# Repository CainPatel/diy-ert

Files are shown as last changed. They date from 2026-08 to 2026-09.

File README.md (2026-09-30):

# diy-ert

<!-- photo of the breadboard build / field setup goes here -->

A four electrode earth resistivity meter (Wenner array) built from scratch
in about a month, for roughly $150 in parts. Commercial instruments that
make the same measurement start above $20,000.

This repo is written as an engineering log. Four ADS1115 ADCs died during
development, all from the same root cause, and the
[failure log](docs/failure-log.md) is probably the most useful file here.
Read it before powering anything up.

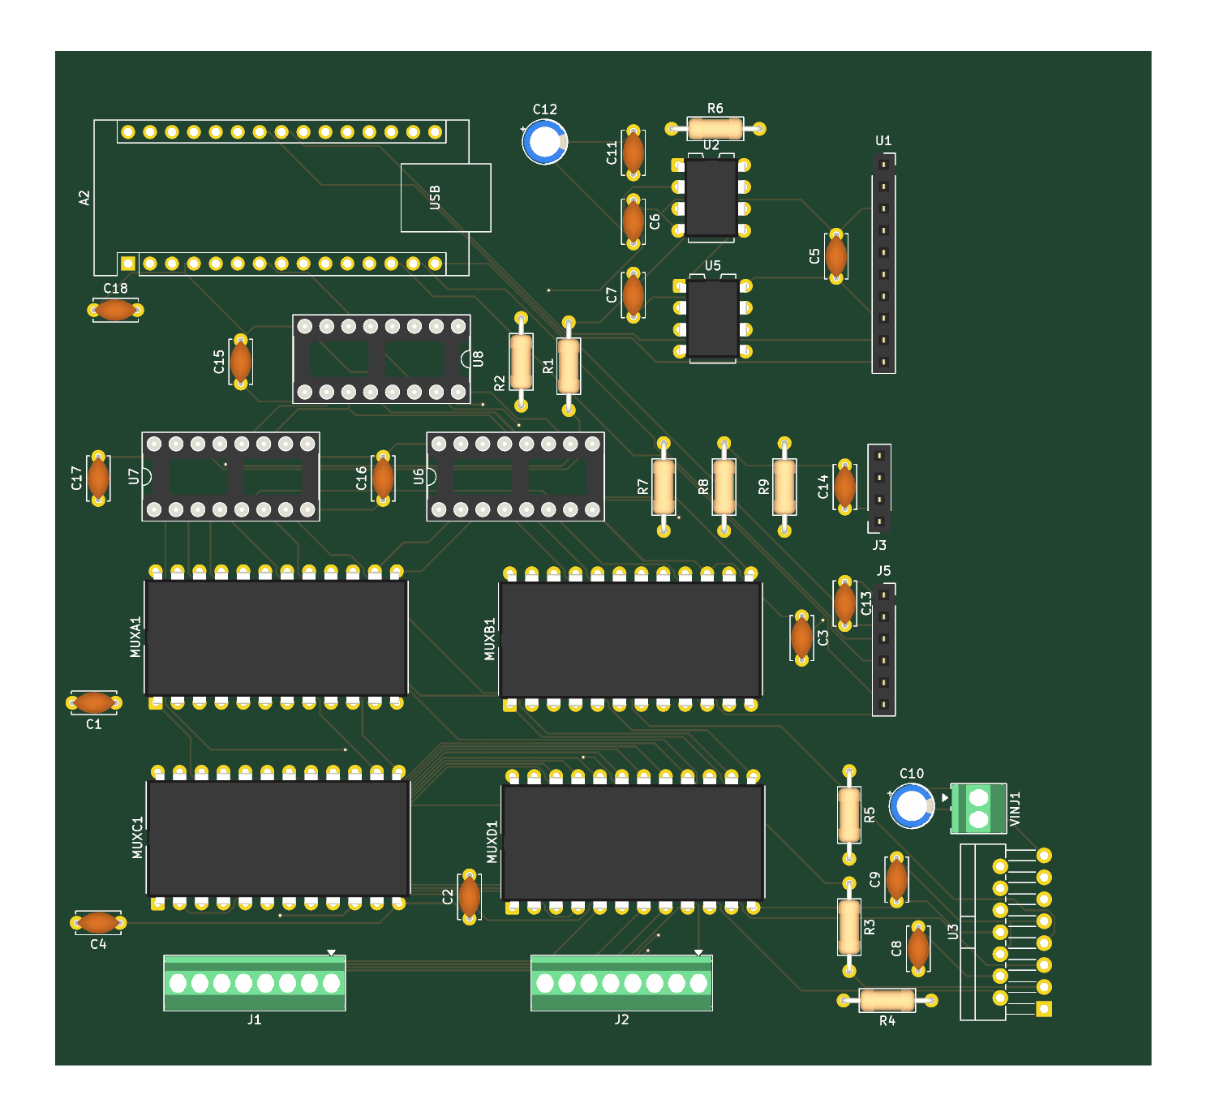
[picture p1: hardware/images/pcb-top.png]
Custom PCB, top side


The custom PCB, designed after the breadboard build below produced its
results. KiCad sources, gerbers, renders and review notes are in
[hardware/](hardware/README.md).

## Results

| Test | Result |
|---|---|
| Bench, known 100 Ω resistor | measured 98.6 Ω (1.4% error) |
| Field, moist Georgia clay, a = 0.5 m | 71-72 Ω·m apparent resistivity, 1.24 mA injected |

No 2D image yet. What exists today is a validated single point measurement
and one good field reading, both from the breadboard build. Full status
below.

## How it works

Contact resistance is the whole problem. Where a steel rod meets soil this
build measured 40-80 kΩ, and a two electrode measurement puts that
directly in series with the tens of ohms of ground you actually want. So
the roles are split across four electrodes: current goes in through the
outer pair (C1, C2), and the voltage it creates in the ground is read
across a separate inner pair (P1, P2). The potential pair feeds an
instrumentation amplifier and draws essentially no current, so its contact
resistance drops no voltage and falls out of the result. On the current
side, contact resistance only limits how much current flows, and the
current is measured across a shunt rather than assumed.

From there it is Ohm's law: R = V/I, and apparent resistivity
ρ = 2πa·R for electrode spacing a. Details in [docs/theory.md](docs/theory.md).

```mermaid
flowchart LR
    mega[Arduino]
    bridge[L298N H-bridge]
    muxa[MUX A]
    muxb[MUX B]
    muxcd[MUX C and D]
    amp[AD620]
    shunt["1 kΩ shunt"]
    adc[ADS1115]
    earth((earth))

    mega -->|IN1, IN2| bridge
    bridge --> muxa -->|C1| earth
    earth -->|C2| muxb --> shunt --> bridge
    earth -->|P1, P2| muxcd --> amp -->|A0| adc
    shunt -.->|A2, A3| adc
    adc -.->|I2C| mega
```

The H-bridge flips the injection polarity every ~150 ms. Differencing the
two half cycles cancels electrode self-potential and amplifier offset, and
stacking 20 cycles averages the noise down. The AD620 stage gain is 76 on
the breadboard build, measured with a multimeter during calibration rather
than taken from the trimmer setting. Four 16-channel muxes let any of 16
electrodes play any of the four roles.

## Status

- [x] Bench validation against a known resistor
- [x] One field reading
- [x] 16 channel electrode switching built on the breadboard, 12 of 16
      channels working (contact faults, see the failure log)
- [x] Automated Wenner survey firmware, outputs pyGIMLi format
- [x] Custom PCB designed: Arduino Nano plus shift registers, 2 layers,
      DRC clean, gerbers generated, firmware written and compiled
- [x] PCB fabricated, assembled and brought up (one design issue to settle
      first, see the review notes in [hardware/](hardware/README.md))
- [ ] Non-polarising potential electrodes (steel rods drift within minutes)
- [ ] 2D survey of real ground

## Documentation

In reading order:

1. [Theory](docs/theory.md): Ohm's law through the ground, Wenner
   geometry, why the polarity alternates, why stacking works
2. [Hardware](docs/hardware.md): the signal chain, wiring reference, and
   five design constraints learned the hard way
3. [Calibration](docs/calibration.md): the offset/gain procedure in the
   order that converges, with the numbers from this build
4. [Failure log](docs/failure-log.md): symptom, root cause, and fix for
   every failure, including the four dead ADCs
5. [Field procedure](docs/field-procedure.md): how the field reading was
   taken and what limits survey duration
6. [Build guide](docs/assembly.md): power, physical layout, every
   connection pin by pin, assembly order, pre-power checklist
7. [Software guide](docs/software.md): toolchain, uploading, the
   bring-up walkthrough, capturing a survey, running the inversion
8. [Firmware](firmware/README.md): seven bring-up sketches for the
   breadboard and one for the PCB. Run them in order.
9. [PCB](hardware/README.md): the board, what changed from the
   breadboard, shift register wiring, BOM, fabrication, review notes

## Repository layout

```
diy-ert/
├── docs/          theory, hardware, calibration, failure log, field
│                  procedure, build guide, software guide
├── firmware/      bring-up sketches 00-06 (Mega breadboard), 07 (Nano PCB)
├── hardware/      PCB: KiCad sources, gerbers, renders, schematic PDF,
│                  BOM, DRC/ERC reports
├── analysis/      pyGIMLi inversion script, capture cleaner, format notes
└── data/          data format spec and the one validated field reading
```

## Cost

Roughly $150 in parts including spares. The PCB bill of materials is in
[hardware/README.md](hardware/README.md); the parts that are not on the
board (rods, supply, wire, the breadboard-only trimmers) are listed in
the [build guide](docs/assembly.md).

## License

MIT, see [LICENSE](LICENSE).

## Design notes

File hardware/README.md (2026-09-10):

# Hardware

The electrical design and the breadboard wiring reference are in
[docs/hardware.md](../docs/hardware.md); the physical build guide for
both versions is [docs/assembly.md](../docs/assembly.md). This directory
holds the custom PCB: KiCad sources, fabrication files, reports, images,
and the bill of materials.

PCB, top side

## Status

- [x] Schematic complete; ERC run, 5 errors and 22 warnings, all explained below
- [x] Layout routed on 2 layers; DRC clean apart from one silkscreen overlap
- [x] Gerbers and drill file generated from the board sources
- [ ] Boards fabricated
- [ ] Board assembled and brought up with [sketch 07](../firmware/07_pcb_console/)
- [ ] Bench result reproduced on the PCB (98.6 Ω on the 100 Ω reference)

Before ordering, read the review notes at the end of this page. One of
them (the ADS1115 socket pin order) needs a decision.

## Board at a glance

| | |
|---|---|
| Tool | KiCad 10.0.5, sources in [kicad/](kicad/) |
| Size | 127.05 x 117.55 mm, 2 layers, 1.6 mm FR4 |
| Parts | 44 footprints, all through-hole; every IC in a DIP socket |
| Controller | Arduino Nano v3 on headers, powered over USB |
| Control lines | 3 (SER, SRCLK, RCLK) into a chain of three 74HC595s, replacing the Mega's 18 direct pins |
| Design rules | 0.2 mm track, 0.15 mm clearance, 0.6 mm vias, 0.5 mm copper-to-edge |
| Copper | ground pour on the bottom layer, 840 track segments, 17 vias |
| Connectors | two 8-way screw terminals for electrodes E0-E15, 2-way screw terminal for the injection supply, I2C header, SPI header |
| Reports | [reports/drc.rpt](reports/drc.rpt), [reports/erc.rpt](reports/erc.rpt) |
| Schematic | [schematic.pdf](schematic.pdf), [images/schematic.png](images/schematic.png) |
| BOM | [bom.csv](bom.csv), exported from the schematic |

## What changed from the breadboard

| | Breadboard (validated) | PCB |
|---|---|---|
| Controller | Arduino Mega, 18 direct control pins | Arduino Nano, 3 pins into three 74HC595 shift registers |
| Bridge control | two Mega pins to L298N IN1/IN2 | U8 outputs QA/QB to IN1/IN2 |
| L298N | driver module | bare L298N (Multiwatt-15) on the board, EnA tied high, bridge B unused |
| Amplifier gain | 10 kΩ trimmer, measured 76 | fixed R6 = 1 kΩ, 50.4 nominal, no trimmer |
| Offset / reference | trimmer into the LM358 buffer | fixed 10k/10k divider (R7/R8) into the LM358 buffer, 2.5 V |
| ADS1115 | breakout on the breadboard | same breakout plugged into a 10-pin socket, U1 |
| Protection | 10 kΩ on ADC inputs | 10 kΩ on every ADC input (R4, R5, R9) and both amplifier inputs (R1, R2) |
| Electrodes | jumper wires | screw terminals J1 (E0-E7), J2 (E8-E15) |
| Decoupling | some | 100 nF at every IC, 10 µF on the 5 V rail, 100 µF + 100 nF on the injection supply |

No trimmers means calibration on the PCB reduces to measuring the gain
(step 4 of [docs/calibration.md](../docs/calibration.md)). If the
amplifier saturates, lower the injection voltage or increase R6.

## Floorplan

Top view, matching the render above. The Nano sits in the top-left
corner with its USB connector facing into the board. The three shift
registers are below it (U8 directly under the Nano, U7 and U6 in a row
beneath). The analog front end is in the top-right: the AD620 (U2) with
its gain resistor R6 above it, the LM358 reference buffer (U5) below it,
and the ADS1115 socket (U1) at the right edge. The sense-side protection
resistors R1/R2 sit between the shift registers and the amplifier; the
reference divider R7/R8 and the output protection R9 are to their right.
The four muxes form a 2x2 block in the lower half (A and B on top, C and
D below) with the electrode terminals J1 and J2 on the bottom edge
directly beneath them. The injection parts are grouped in the
bottom-right corner: the L298N (U3, upright at the right edge), the
injection terminal VINJ1, the 100 µF bulk capacitor C10, the shunt R3,
and its protection resistors R4/R5. The I2C header J3 and SPI header J5
are on the right edge, mid-board.

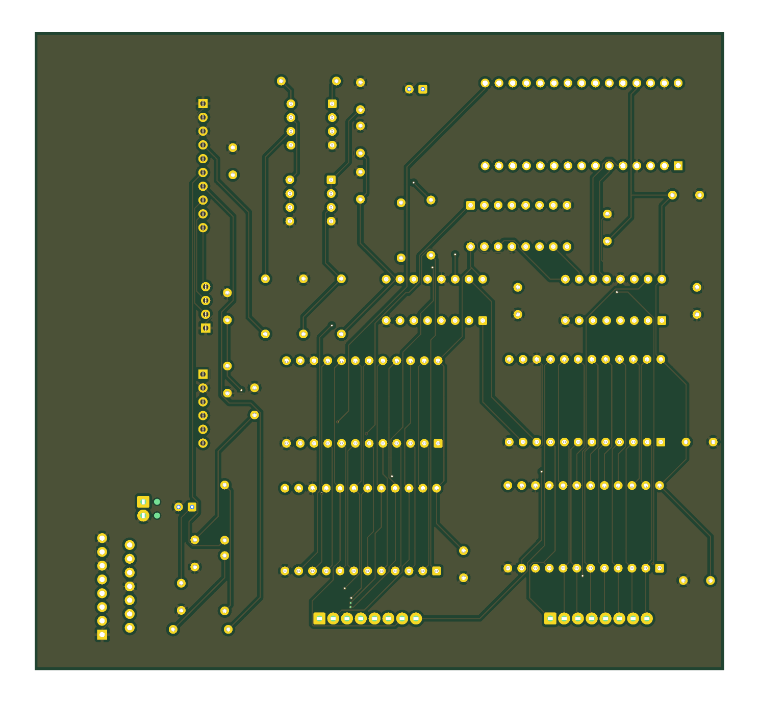
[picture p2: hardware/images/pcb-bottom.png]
PCB, bottom side


## Shift register chain

This is the part the firmware has to get right.

Nano D2 clocks SRCLK on all three registers, D3 clocks RCLK on all three,
and D4 feeds SER of U6. U6's QH' feeds U7's SER, and U7's QH' feeds U8's
SER. Output enable (~OE) is tied to ground on all three, so the outputs
are always driven; ~SRCLR is tied to 5 V.

| Register | Outputs | Drives |
|---|---|---|
| U6 | QA, QB, QC, QD | MUX A (C1) S0, S1, S2, S3 |
| U6 | QE, QF, QG, QH | MUX B (C2) S0, S1, S2, S3 |
| U7 | QA, QB, QC, QD | MUX C (P1) S0, S1, S2, S3 |
| U7 | QE, QF, QG, QH | MUX D (P2) S0, S1, S2, S3 |
| U8 | QA, QB | L298N IN1, IN2 |
| U8 | QC-QH | unused |

Shifting 24 bits MSB-first, U8's byte first, then U7's, then U6's, puts
bit 0 of each byte on that register's QA. So U6's byte is
`chA | (chB << 4)`, U7's is `chC | (chD << 4)`, and U8's is
`IN1 | (IN2 << 1)`. Sketch 07 does exactly this in `latch()`.

## Nano pin map

| Nano | Net |
|---|---|
| D2 | 74HC595 SRCLK (all three) |
| D3 | 74HC595 RCLK (all three) |
| D4 | 74HC595 SER, into U6 |
| A4, A5 | I2C SDA, SCL: ADS1115 and header J3 |
| D10, D11, D12, D13 | SPI CS, MOSI, MISO, SCK: header J5 only, unused by the firmware |
| 5V, GND | board logic supply, from the Nano's USB |
| VIN, 3V3, D0-D1, D5-D9, A0-A3, A6-A7 | not connected |

## Connectors

| Ref | Type | Pin 1 to pin N |
|---|---|---|
| J1 | 8-way screw terminal, 2.54 mm | E0, E1, E2, E3, E4, E5, E6, E7 |
| J2 | 8-way screw terminal, 2.54 mm | E8, E9, E10, E11, E12, E13, E14, E15 |
| VINJ1 | 2-way screw terminal | injection supply +, GND |
| J3 | 1x4 socket | GND, 5V, SDA, SCL |
| J5 | 1x6 socket | 5V, GND, MISO (D12), MOSI (D11), SCK (D13), CS (D10) |
| U1 | 1x10 socket | see the review notes below before fitting a breakout |

## Bill of materials

From the KiCad schematic ([bom.csv](bom.csv)), with approximate
single-unit prices.

| Ref | Qty | Part | Package | ~Price |
|---|---|---|---|---|
| A2 | 1 | Arduino Nano v3 (clone) | module, on 1x15 headers | $5 |
| U1 | 1 | ADS1115 breakout | 1x10 socket | $10 |
| U2 | 1 | AD620AN | DIP-8 | $10 |
| U3 | 1 | L298N | Multiwatt-15 (TO-220-15), vertical | $3 |
| U5 | 1 | LM358 | DIP-8 | $1 |
| U6, U7, U8 | 3 | 74HC595 | DIP-16 | $1 ea |
| MUXA1-MUXD1 | 4 | CD74HC4067E | DIP-24 | $2 ea |
| R1, R2, R4, R5, R7, R8, R9 | 7 | 10 kΩ | axial | |
| R3 | 1 | 1 kΩ 1%, shunt | axial | |
| R6 | 1 | 1 kΩ, AD620 gain | axial | |
| C1-C9, C11, C13-C18 | 16 | 100 nF ceramic | 5 mm disc | |
| C10 | 1 | 100 µF electrolytic | radial, 2.5 mm pitch | |
| C12 | 1 | 10 µF electrolytic | radial, 2.5 mm pitch | |
| J1, J2 | 2 | 8-way screw terminal, 2.54 mm (Phoenix MPT 0,5/8) | | $2 ea |
| VINJ1 | 1 | 2-way screw terminal, 2.54 mm | | $1 |
| J3, J5 | 2 | 1x4 and 1x6 pin sockets | | |
| | 9 | DIP sockets: 2x 8-pin, 3x 16-pin, 4x 24-pin | | $3 |
| | 1 | bare 2-layer PCB from any prototype fab | | $5-10 for five |

Breadboard-only extras (trimmers, breadboards, jumpers) and the parts
common to both builds (electrode rods, 12 V supply, wire) are in
[docs/assembly.md](../docs/assembly.md). The whole build still lands
near $150.

## Fabrication

[gerbers/](gerbers/) has the seven layer files, the drill file, and the
job file, generated from `kicad/diy-ert.kicad_pcb` with `kicad-cli` (the
exact commands are in [kicad/README.md](kicad/README.md)). Zip the
directory and upload it; the board needs nothing beyond any prototype
fab's defaults: 2 layers, 1.6 mm, 0.2 mm minimum track, 0.15 mm
clearance, HASL finish is fine.

The set exported on 2026-08-29 predates the last save of the board file
by a couple of hours, so the committed set is regenerated from the board
as saved. Compared line by line with aperture numbering normalised, the
two sets are geometrically identical: same apertures, same pads, same
tracks on every layer. The only difference is one unused aperture
selection in the older copper and mask files.

## History

- 2026-08-22 to 08-24: schematic drawn around the Mega, netlist exported
  repeatedly while footprints were assigned and the amplifier stage
  added.
- Around 08-25: a 4-layer layout attempt. An autorouter round trip
  produced 686 DRC violations (201 net shorts, 199 dangling tracks) from
  a layer-mapping mismatch on re-import. Lesson: autorouters do not know
  which nets are noise-sensitive; hand-route the analog paths and lock
  them, or hand-route everything on a board this size.
- 2026-08-29: redesign around the Nano and three 74HC595s, taking the
  control pin count from 18 to 3. Two-layer layout, Freerouting DSN
  export, DRC with one silkscreen warning, gerbers exported, board saved.

## Review notes

Things noticed while reading the design files for this write-up. None
have been tested on a physical board yet.

1. **ADS1115 socket pin order.** U1 uses the ADS1115 chip symbol with a
   1x10 pin-socket footprint, so the socket pins follow the IC's pin
   numbering: ADDR, ALERT, GND, A0, A1, A2, A3, VDD, SDA, SCL from pin 1
   to pin 10. The common breakout modules (Adafruit and the clones) have
   their header in the order VDD, GND, SCL, SDA, ADDR, ALRT, A0, A1, A2,
   A3. Plugged straight in, a standard breakout would put its VDD on the
   pad that is wired to ground. Before ordering, either swap the symbol
   for one that matches the breakout header, or plan on an adapter
   between the socket and the module. Check your specific module's
   silkscreen against this list.
2. **Shift register outputs at power-on.** ~OE is tied to ground on all
   three 74HC595s, so their outputs drive the mux select lines and the
   L298N inputs from the moment power arrives, with undefined contents,
   until the firmware latches a state. Sketch 07 does that first thing in
   `setup()`, but the Nano bootloader runs for about a second before it.
   A future revision could drive ~OE from a Nano pin with a pull-up so
   the outputs stay high-impedance until the firmware takes over. Until
   then, power the logic before connecting the injection supply.
3. **Fixed gain.** R6 = 1 kΩ gives a nominal gain of 50.4 with the
   reference at 2.5 V. The field reading of 28.5 mV across P1-P2 would
   swing the output by about 1.4 V either side of 2.5 V, which is inside
   the AD620's output range on a 5 V supply but not by a lot. Larger
   signals need a lower injection voltage or a larger R6. The `t`
   command in sketch 07 flags readings near the rails.
4. **C10 polarity.** C10 (100 µF on the injection supply) is drawn with a
   plain capacitor symbol but has a polarised footprint. Fit it with the
   positive lead to the VINJ1 side.
5. **I2C pull-ups.** There are none on the board; the ADS1115 breakout
   provides them. A bare chip in U1 would need them added.
6. **Silkscreen.** The one DRC warning is U2's reference designator
   overlapping R6's outline. Cosmetic.
7. **ERC.** The five errors are all "pin not driven": the Nano's VIN,
   both RESET pins, and AREF (unused, normal for that symbol), and the
   L298N's Vs, which enters through the VINJ1 connector and would be
   silenced by a PWR_FLAG on that net. The warnings are unused pins
   (Nano, L298N bridge B, ADS1115 ALERT, U8 QC-QH), one short wire stub
   near the Nano's 3V3 pin, and "Vss not connected to ground": the KiCad
   L298N symbol names its logic-supply pin Vss, and it is correctly on
   5 V.
8. **Track width.** 0.2 mm everywhere, including the 5 V and injection
   paths. Fine for the currents involved (about a milliampere of
   injection, tens of milliamperes of logic) and for any fab, but thin
   for hand rework. A future revision could widen the supply traces.

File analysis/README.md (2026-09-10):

# Analysis

Inversion of survey output with [pyGIMLi](https://www.pygimli.org/), and
a helper for turning a raw serial capture into a data file.

## Install and run

pyGIMLi installs cleanly through conda:

```
conda create -n ert -c gimli -c conda-forge pygimli
conda activate ert
python invert_pygimli.py survey.dat        # lam = 20
python invert_pygimli.py survey.dat 50     # smoother
```

`clean_capture.py` needs only Python:

```
python clean_capture.py capture.txt survey.dat
```

It keeps the data block (from the electrode-count line to the closing
`0`) and drops the banner and command replies that sketch 07 prints
around it. Sketch 06 prints nothing but the data, so its capture can be
used directly.

## Data format

Firmware sketches 06 and 07 emit pyGIMLi's unified data format directly:

```
12
# x z
0.00 0.0
0.50 0.0
...
18
# a b m n rhoa
1 4 2 3 72.196
...
0
```

- The header block declares the electrode positions in metres (12
  electrodes at 0.5 m spacing for the breadboard build's working
  channels; 16 by default on the PCB).
- Each data row is `a b m n rhoa`. **a/b are the current electrodes, m/n
  are the potential pair**, and electrode numbers are **1-indexed**. An
  off-by-one here does not error out; it silently produces a wrong but
  plausible-looking model.
- `rhoa` is apparent resistivity in Ω·m, computed in the firmware as
  2πa·R from the measured V and I.
- The trailing `0` is the empty topography block.

## Regularisation

The surveys are small: 12 working electrodes give 9 + 6 + 3 = 18 Wenner
readings across three spacings, and 16 electrodes give 35 across five.
With that little data the regularisation parameter `lam` matters a great
deal. Too low and the inversion fits noise, producing structure that is
not in the ground. The default is `lam=20`. A useful habit with data
this sparse: treat any feature that disappears when you double `lam` as
an artefact.

## Status

The pipeline is written against the firmware's output format but has not
been run on a real 2D field dataset. The instrument so far has one
validated single point field reading, not a survey. See the
[repository README](../README.md).

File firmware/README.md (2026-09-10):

# Firmware

Seven sketches that bring the breadboard instrument up one verified
subsystem at a time, plus one sketch for the custom PCB. The end-to-end
walkthrough (toolchain, uploading, what to type, capturing output) is in
[docs/software.md](../docs/software.md).

> [!WARNING]
> **Run the sketches in order.** Every hardware failure on this project,
> including four destroyed ADS1115s, came from powering up an unverified
> circuit. Each sketch verifies one subsystem against an independent
> reference (a multimeter, a known resistor) before the next subsystem
> goes on top.

| # | Sketch | Board | Verifies | Failure signature |
|---|---|---|---|---|
| 00 | [I2C scanner](00_i2c_scanner/) | Mega or Nano | ADC is alive at 0x48 | nothing found: check power, SDA/SCL, solder |
| 01 | [Raw ADC readout](01_raw_adc/) | Mega or Nano | ADC reads a known voltage correctly | raw counts near 0 on A2/A3: shunt sense wires disconnected |
| 02 | [DC hold](02_dc_hold/) | Mega | H-bridge switches; lets a multimeter settle | trace voltage along the path, find where it disappears |
| 03 | [Mux channel scan](03_mux_scan/) | Mega | Address decoding and channel continuity | all channels identical: read the mux output directly, not through the amp |
| 04 | [Live amp tuning](04_amp_tuning/) | Mega | Amp operating in range | both halves near 3.6 V: saturated, adjust offset first, not gain |
| 05 | [Single measurement](05_single_measurement/) | Mega | Whole chain, against a known resistor | should report ~100 Ω on a 100 Ω target |
| 06 | [Wenner survey](06_wenner_survey/) | Mega | Full sequence over working channels | outputs pyGIMLi format rows |
| 07 | [PCB console](07_pcb_console/) | Nano (PCB) | steps 01-06 as serial commands, through the shift registers | see its README |

Sketches 00-06 are the breadboard build (Arduino Mega, 18 direct control
pins). Sketch 07 is the PCB (Arduino Nano, 3 pins into three 74HC595
shift registers), where one sketch with a command per step replaces
02-06; 00 runs unchanged on the Nano first.

All eight compile cleanly with arduino-cli 1.5 and AVR core 1.8.8
(00-06 for `arduino:avr:mega`, 00, 01 and 07 for `arduino:avr:nano`).

## Requirements

- Arduino IDE or arduino-cli, with the **Adafruit ADS1X15** library
  installed (Library Manager, search "Adafruit ADS1X15"; accept the
  Adafruit BusIO dependency). Sketches 00, 02 and 03 need only the core
  libraries.
- Serial monitor at 9600 baud.
- Some Arduino IDE versions refuse sketch folders that start with a
  digit. If yours does, rename the folder and the `.ino` together (for
  example `s00_i2c_scanner/s00_i2c_scanner.ino`) and keep the ordering
  prefix.

## Pin map, breadboard (Arduino Mega)

| Function | Pins |
|---|---|
| L298N IN1 / IN2 | 6, 7 |
| Mux C1, address S0-S3 | 22, 24, 26, 28 |
| Mux C2, address S0-S3 | 30, 32, 34, 36 |
| Mux P1, address S0-S3 | 38, 40, 42, 44 |
| Mux P2, address S0-S3 | 46, 48, 50, 52 |
| ADS1115 | SDA = 20, SCL = 21, address 0x48; A0 = amp output, A2/A3 = shunt |

18 control pins total (16 mux address lines + 2 bridge inputs).

## Pin map, PCB (Arduino Nano)

| Function | Pins |
|---|---|
| 74HC595 SRCLK, RCLK, SER | D2, D3, D4 |
| ADS1115 | SDA = A4, SCL = A5, address 0x48 |
| Mux select lines and L298N IN1/IN2 | from the shift registers; chain order and bit layout in [hardware/README.md](../hardware/README.md) |

## Implementation details that carry the lessons

These are deliberate. Keep them if you modify the code:

- The stacking accumulators are explicitly initialised to zero.
  Uninitialised floats in C++ contain garbage, and garbage accumulated
  over 20 cycles looks like a plausible measurement. This bug happened.
- The shunt is read in both polarities and the magnitudes averaged, so
  bridge asymmetry and differential offset average out of the current
  value.
- The bridge is parked with both inputs LOW between measurements, to
  limit electrode polarisation
  ([docs/field-procedure.md](../docs/field-procedure.md)).
- The survey runs from `loop()` behind a done-flag, not from `setup()`,
  and waits for a start command, so output is not lost if the serial
  monitor opens late.
- A `CH[]` lookup table maps physical electrode position to a working mux
  channel, so dead channels are invisible to the survey logic:

```cpp
// Working channel map from the physical build
// Dead: 0, 7, 11, 12 (breadboard contact faults)
const int CH[12] = {1,2,3,4,5,6,8,9,10,13,14,15};
```

- On the PCB, `setup()` latches a parked bridge into the shift registers
  before anything else, because their outputs are live from power-on
  with undefined contents.

## Calibration constants

`AMP_GAIN` is a measured value, not a design constant: 76 on the
breadboard build, (3.5483 - 0.8205) / 0.0358; 50.4 nominal on the PCB
from R6 = 1 kΩ, to be measured. Run the procedure in
[docs/calibration.md](../docs/calibration.md) and substitute your own
value. Same for the shunt: measure its actual resistance rather than
trusting the band code.

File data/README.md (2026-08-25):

# Data

## Format

Two kinds of records belong in this directory:

**Survey files (`*.dat`):** the verbatim serial capture from firmware
sketch 06, in pyGIMLi's unified data format. The layout is documented in
[analysis/README.md](../analysis/README.md).

**Single manual readings:** commented blocks, one per measurement,
carrying every raw value needed to recompute the result:

```
# Wenner array, a = 0.5 m, Georgia clay soil, moist
# I = 1.24 mA, V(P1-P2) = 28.5 mV
# R = 22.98 Ω, ρ = 2πaR = 72.20 Ω·m
```

Each number states how it was obtained. `I` is measured across the 1 kΩ
shunt. `V(P1-P2)` is the stacked, offset-cancelled amplifier reading
divided by the measured gain. `R = V/I`. `ρ = 2πaR` is computed from
those, not measured.

## The one validated field reading

The block above is it, the single successful field measurement this
instrument has produced: Wenner array at a = 0.5 m in moist Georgia
clay, 1.24 mA injected, 28.5 mV across the potential pair, giving
R = 22.98 Ω and an apparent resistivity of 72.20 Ω·m.

## Known caveat: polarisation drift

Readings drifted from 71 to 90 Ω·m over several minutes as the steel
potential electrodes polarised. The 71-72 Ω·m value is the prompt
reading, taken before drift set in. Non-polarising copper sulphate
electrodes are the standard fix and are cheap to build. Until then, the
drift bounds how long a survey can run before it turns into a false
gradient in the data. Details in
[docs/field-procedure.md](../docs/field-procedure.md).

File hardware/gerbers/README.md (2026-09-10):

# Fabrication files

Generated from `../kicad/diy-ert.kicad_pcb` with `kicad-cli` (commands in
[../kicad/README.md](../kicad/README.md)).

| File | Layer |
|---|---|
| `diy-ert-F_Cu.gbr`, `diy-ert-B_Cu.gbr` | top and bottom copper |
| `diy-ert-F_Mask.gbr`, `diy-ert-B_Mask.gbr` | solder mask |
| `diy-ert-F_Silkscreen.gbr`, `diy-ert-B_Silkscreen.gbr` | silkscreen |
| `diy-ert-Edge_Cuts.gbr` | board outline |
| `diy-ert.drl` | Excellon drill, plated and non-plated together |
| `diy-ert-job.gbrjob` | job file: stackup, size, design rules |

To order: zip this directory and upload it. 2 layers, 1.6 mm,
127.05 x 117.55 mm, 0.2 mm minimum track, 0.15 mm clearance. Read the
review notes in [../README.md](../README.md) first.

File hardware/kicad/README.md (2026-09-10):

# KiCad project

KiCad 10.0.5 sources for the diy-ert board.

| File | What |
|---|---|
| `diy-ert.kicad_pro` | project settings, design rules, net classes |
| `diy-ert.kicad_sch` | schematic, one A4 sheet |
| `diy-ert.kicad_pcb` | board, 2 layers, 127.05 x 117.55 mm |

Open `diy-ert.kicad_pro` in KiCad 10 or newer. Every symbol and footprint
comes from the standard KiCad libraries, so nothing else needs installing.
The `.kicad_prl` file (per-machine view settings) and the `.history/`
backup directory that KiCad creates are ignored by git.

The project was drawn under the default name `Untitled` and renamed here;
the rename touched only the project-name strings in the files, and the
netlist, ERC, DRC, and gerbers exported from the renamed project match the
originals.

## Regenerating the exports

Everything in the parent directory (schematic PDF, board renders, BOM,
reports, gerbers) is produced from these sources with `kicad-cli`:

```
kicad-cli sch export pdf -o ../schematic.pdf diy-ert.kicad_sch
kicad-cli sch export bom -o ../bom.csv --fields "Reference,Value,Footprint,\${QUANTITY}" --group-by "Value,Footprint" diy-ert.kicad_sch
kicad-cli sch erc -o ../reports/erc.rpt --severity-all diy-ert.kicad_sch
kicad-cli pcb drc -o ../reports/drc.rpt --severity-all diy-ert.kicad_pcb
kicad-cli pcb render -o ../images/pcb-top.png --side top --width 1500 --height 1400 diy-ert.kicad_pcb
kicad-cli pcb render -o ../images/pcb-bottom.png --side bottom --width 1500 --height 1400 diy-ert.kicad_pcb
kicad-cli pcb export gerbers -o ../gerbers/ --no-protel-ext --layers "F.Cu,B.Cu,F.SilkS,B.SilkS,F.Mask,B.Mask,Edge.Cuts" diy-ert.kicad_pcb
kicad-cli pcb export drill -o ../gerbers/ diy-ert.kicad_pcb
```

On macOS `kicad-cli` lives at
`/Applications/KiCad/KiCad.app/Contents/MacOS/kicad-cli`.

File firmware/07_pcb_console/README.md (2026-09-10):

# 07: PCB console

**Target:** the custom PCB in [hardware/](../../hardware/), Arduino Nano.
Sketches 00-06 target the Mega breadboard build and drive the mux select
lines and the H-bridge from 18 direct pins. On the PCB those 18 lines come
from three chained 74HC595 shift registers on 3 Nano pins, so the PCB gets
one sketch with a serial command for each bring-up step instead.

**Board selection:** Arduino Nano. Most clones need Processor set to
"ATmega328P (Old Bootloader)".

**Commands** (9600 baud, any line ending):

| Command | Does | Replaces breadboard sketch |
|---|---|---|
| `?` | print this list | |
| `r` | one raw ADC readout: A0 and A2-A3, counts and volts | 01 |
| `p` | park the bridge, both L298N inputs low | 02 |
| `+` / `-` | hold the bridge forward / reverse in DC, for multimeter work | 02 |
| `c N` | put all four muxes on channel N (0-15) | 03 |
| `x A B C D` | set channels individually: C1=A, C2=B, P1=C, P2=D | |
| `t` | live amplifier readout, alternating polarity; any key stops | 04 |
| `m` | one stacked measurement on the current channels, prints R | 05 |
| `w` | Wenner survey over `CH[]`, prints a pyGIMLi data file | 06 |

Sketch 00 (I2C scanner) runs unchanged on the Nano and is still the first
thing to run.

**Constants to check before use:** `AMP_GAIN` (the PCB fixes the AD620
gain with R6 = 1 kΩ, 50.4 nominal; measure it per
[docs/calibration.md](../../docs/calibration.md)), `SHUNT_OHMS` (measure
R3), `ELECTRODE_SPACING`, and `CH[]` if the `c` scan finds a bad channel.

**Bring-up order on the PCB:** with no ICs fitted, check the 5 V rail.
Fit the Nano and the ADS1115 breakout, run sketch 00. Load this sketch,
`r` to confirm the ADC reads. Fit the shift registers and the L298N with
the injection supply off, `+`/`-`/`p` and confirm IN1/IN2 toggle at the
L298N pins. Fit the muxes, `c N` and beep out continuity from each mux
common pin to terminal E N. Fit the AD620 and LM358, `t` with the bench
chain. Then `m` on the known resistor. Details in
[docs/software.md](../../docs/software.md).

**What the suspect flag means:** `t` and `m` mark a reading as suspect
when the two half-cycles read nearly the same voltage (amplifier
saturated, or an input floating) or when the output sits within 0.2 V of
a rail. Both were real failure modes on the breadboard build. There are no
trimmers on the PCB: if the amp saturates, lower the injection voltage or
raise R6 to reduce the gain.

**Power-on note:** the 595 outputs are enabled from power-on (their
output-enable pin is tied to ground on the board) with undefined
contents. `setup()` latches a parked bridge and known mux channels first
thing, but the bootloader runs for about a second before that. Power the
logic before connecting the injection supply.

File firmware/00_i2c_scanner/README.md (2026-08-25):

# 00: I2C scanner

**Verifies:** the ADS1115 is alive and answering at address 0x48. Run
this before anything else. It needs only the Arduino, the ADS1115
breakout, and two I2C wires.

**Expected output:** `Device found at 0x48`, repeated every five seconds.

**Failure signature:** nothing found. Check, in this order:

1. Power to the breakout (VDD and GND with a multimeter, at the chip
   side of the header, not the wire side)
2. SDA/SCL wiring. Mega: SDA = pin 20, SCL = pin 21
3. The solder joints on the breakout headers

Press-fitted, unsoldered header pins pass visual inspection and fail
electrically. That exact fault produced several days of intermittent I2C
on this build ([docs/failure-log.md](../../docs/failure-log.md)).

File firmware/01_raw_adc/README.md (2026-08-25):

# 01: Raw ADC readout

**Verifies:** the ADS1115 converts a known voltage correctly, on the
inputs this instrument actually uses: A0 single-ended (amplifier output)
and A2/A3 differential (current shunt).

**How to use:** feed A0 a known voltage (the 2.5 V mid-rail node is
convenient) and confirm the printed value against a multimeter on the
same node. Then put a small DC current through the shunt (sketch 02 can
hold the bridge in DC) and check the A2-A3 differential the same way.
Requires the Adafruit ADS1X15 library.

**Failure signature:** raw counts near 0 on A2/A3 while current is
flowing means the shunt sense wires are disconnected.

Do not move on to the amplifier sketches until the ADC agrees with the
multimeter here. Every later sketch reads the world through this chip.

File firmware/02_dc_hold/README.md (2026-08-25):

# 02: DC hold

**Verifies:** the L298N H-bridge switches, and gives a multimeter a
signal it can actually read.

**Why it exists:** a multimeter cannot track a 150 ms square wave. It
averages toward zero and reports "no current" while the bridge is
driving perfectly well. That false reading cost real time on this build
([docs/failure-log.md](../../docs/failure-log.md)). Park the bridge in
DC and the multimeter is trustworthy again.

**How to use:** serial commands `+` (forward), `-` (reverse), `p`
(park). Hold a polarity and trace the voltage along the injection path
(supply, bridge OUT1/OUT2, mux input, electrode) until it disappears. A
jumper wire that had failed internally with no visible damage was found
exactly this way.

**Also worth doing here:** measure the actual voltage across OUT1-OUT2
at your working current. On this build the nominal 5 V supply delivered
only 3.8 V. The L298N's drop is current-dependent, and assuming the
nominal value produced a 45% error in computed resistance
([docs/hardware.md](../../docs/hardware.md), constraint 5).

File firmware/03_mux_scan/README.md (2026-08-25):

# 03: Mux channel scan

**Verifies:** address decoding and channel continuity on all four
CD74HC4067 multiplexers.

**How to use:** the sketch steps all four muxes through channels 0-15
together, two seconds per channel, announcing each on serial. For each
announced channel, continuity-beep from the mux's common pin to the
corresponding electrode header. Record every channel that fails.

**Failure signature:** all channels reading identically at the ADC. Read
the mux common pin directly with the multimeter, not through the
amplifier. A saturated amp makes every channel look the same regardless
of what the mux does (see the 3.62 V entry in
[docs/failure-log.md](../../docs/failure-log.md)).

**From this build:** channels 0, 7, 11 and 12 were dead. Breadboard
contact faults, not chip or addressing faults. The diagnostic that ruled
out the chips: in binary the dead channels are 0000, 0111, 1011 and
1100, which share no common address bit, so no single stuck address line
can explain them. The survey firmware routes around dead channels with
the `CH[]` lookup table ([firmware/README.md](../README.md)).

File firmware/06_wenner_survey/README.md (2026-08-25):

# 06: Wenner survey

**Runs:** the full automated measurement sequence over the 12 working
electrode channels, 18 measurements across three Wenner spacings (9 at
a = 0.5 m, 6 at 1.0 m, 3 at 1.5 m), and prints an inversion-ready
dataset in pyGIMLi's unified data format.

**How to use:** open the serial monitor, start logging to a file, then
send `s`. The survey runs from `loop()` behind a done-flag and waits for
the start command, so nothing is lost if the monitor attaches late. The
serial output is the data file; the sketch prints nothing else. Capture
it verbatim as `survey.dat` and feed it to
[analysis/invert_pygimli.py](../../analysis/invert_pygimli.py).

**The `CH[]` table** maps logical electrode position (0-11, twelve
equally spaced rods along the line) to a working mux channel, so the
dead channels (0, 7, 11, 12, breadboard contact faults) are invisible to
the survey logic and the field geometry stays uniform. If your build has
different dead channels, run sketch 03 and edit the table.

**Failure signature:** negative apparent resistivity values are
physically impossible. The amplifier railed in one polarity and produced
a fake differential. Go back to sketch 04, re-centre the offset, reduce
the gain ([docs/failure-log.md](../../docs/failure-log.md)).

**Status note:** the sequence runs and emits well-formed data over the
working channels, but a 2D field survey has not been done yet. See the
[repository README](../../README.md) for status and
[docs/field-procedure.md](../../docs/field-procedure.md) for the
electrode polarisation drift that currently bounds survey duration.

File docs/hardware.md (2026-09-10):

# Hardware

The signal chain, in the order the signal flows through it, plus enough
wiring detail to reproduce the breadboard build. The custom PCB that
implements the same circuit is documented in
[hardware/README.md](../hardware/README.md), with KiCad sources in
[hardware/kicad/](../hardware/kicad/); the full pin-by-pin connection
list for both builds is in [assembly.md](assembly.md).

## Signal chain

| Stage | Part | Role |
|---|---|---|
| Injection | L298N H-bridge | alternates polarity, driven from two Arduino pins |
| Current sense | 1 kΩ shunt, read differentially on ADS1115 A2/A3 | measures the actual injected current |
| Potential sense | AD620 instrumentation amplifier | rejects large common-mode, amplifies the mV differential |
| Reference | LM358 unity-gain buffer on a 10k/10k divider | holds the AD620 REF pin at mid-rail (2.5 V) |
| Digitisation | ADS1115, 16-bit, I2C at 0x48 | reads the amp output on A0 |
| Switching | 4x CD74HC4067, 16 channels each | selects which four of 16 electrodes act as C1/C2/P1/P2 |

## Why four multiplexers

Each measurement needs four electrodes in different roles: two carrying
current, two sensing potential. One mux per role means any electrode can
play any part, which an automated survey needs, since the same rod is a
current electrode in one measurement and a potential electrode in the
next. The cost is control pins: 4 muxes x 4 address lines + 2 bridge
inputs = 18 Arduino pins. The pin map is in
[firmware/README.md](../firmware/README.md).

## Design constraints, learned the hard way

> [!CAUTION]
> Everything in this list was learned by breaking something or by
> measuring nonsense. Item 1 cost four chips.

1. **ADC input limits.** The ADS1115 absolute maximum input is
   VDD + 0.3 V, about 5.3 V. Chain nodes were measured at 6.3 V with 12 V
   injection. Every line crossing from the injection domain into 5 V
   logic gets a 10 kΩ series resistor. Without one, fault current is
   limited only by the chain and the chip's bond wires; with one, about
   170 nA.

2. **Amplifier input range.** The AD620's usable input window is
   -VS + 1.9 V to +VS - 1.4 V. On a 5 V single supply that is roughly
   1.9 V to 3.6 V. Sense nodes outside this window produce readings that
   look plausible and mean nothing.

3. **Symmetric resistor chains.** An asymmetric chain (100 kΩ one side,
   10 kΩ the other) puts the sense nodes at wildly different potentials
   depending on injection polarity: 6.67 V one way, 1.32 V the other, out
   of the amp's window in at least one polarity. A symmetric chain keeps
   both nodes near mid-rail in both polarities.

4. **A single supply amplifier cannot output negative voltages.** With
   REF at 0 V the negative half cycle clamps at the output floor and both
   halves read nearly the same, so the differencing cancels the signal
   along with the offset. REF has to sit at mid-rail. That is what the
   LM358 buffer is for.

5. **Measure, never assume.** The L298N's voltage drop depends on
   current. The nominal 5 V supply delivered 3.8 V across OUT1-OUT2 at
   the working current, and using the nominal value gave a 45% error in
   computed resistance.

## Wiring reference

### Injection path

```
 12 V ----+
          |
      +--------+  OUT1            +-------+
      | L298N  |----------------->| MUX A |-----> C1 rod
 IN1->|        |                  +-------+          |
 IN2->|        |                                  [ earth ]
      |        |  OUT2   1 kΩ     +-------+          |
      |        |<-------/\/\/-----| MUX B |<----- C2 rod
      +--------+        shunt     +-------+
                          |
                 ADS1115 A2 / A3 (differential, via 10 kΩ each)
```

Current leaves OUT1, goes through mux A to the C1 rod, through the
ground, back in at C2, through mux B and the shunt, and returns to OUT2.
Driving IN1/IN2 opposite ways sets the polarity; both low parks the
bridge with no drive.

### Sense path

```
 P1 rod --> MUX C --[10 kΩ]--> IN+ (3) __
                                         \
                                    AD620 >-- OUT (6) --[10 kΩ]--> ADS1115 A0
                                       __/
 P2 rod --> MUX D --[10 kΩ]--> IN- (2)
                               REF (5) <-- LM358 buffer <-- 2.5 V divider
```

### Mid-rail reference

```
 5 V --[10 kΩ]--+--[10 kΩ]-- GND
                |
                +--> LM358 IN+, unity gain --> AD620 REF
```

The AD620 REF pin needs a low impedance drive; a bare divider is not
stiff enough, hence the buffer. The offset trim adjusts this node and the
gain trim is the RG resistance between AD620 pins 1 and 8. The two
interact, which is why the order in [calibration.md](calibration.md)
matters.

### AD620 (DIP-8)

| Pin | Name | Goes to |
|---|---|---|
| 1, 8 | RG | gain trimmer |
| 2 | IN- | MUX D common, via 10 kΩ |
| 3 | IN+ | MUX C common, via 10 kΩ |
| 4 | -VS | GND |
| 5 | REF | LM358 buffer output, 2.5 V |
| 6 | OUT | ADS1115 A0, via 10 kΩ |
| 7 | +VS | 5 V |

### ADS1115 breakout

| Pin | Goes to |
|---|---|
| VDD, GND | 5 V, GND |
| SDA, SCL | Mega 20, 21 |
| ADDR | GND (address 0x48) |
| A0 | AD620 OUT, via 10 kΩ |
| A1 | unused |
| A2, A3 | across the 1 kΩ shunt, via 10 kΩ each |

Solder the breakout headers. Press-fit pins were good for several days of
intermittent I2C on this build.

### CD74HC4067 (x4)

All four muxes are wired the same on the electrode side: the 16 channel
pins go to the 16 electrode headers, EN to GND, S0-S3 to the Arduino (pin
map in [firmware/README.md](../firmware/README.md)). Only the common pin
differs per mux: A to bridge OUT1, B to the shunt, C to AD620 IN+, D to
AD620 IN-.

## The PCB

The same circuit on a 2-layer board, 127 x 118 mm, all through-hole,
with three differences that matter to anyone using the docs above:

- The Arduino Mega and its 18 direct control lines are replaced by an
  Arduino Nano and three chained 74HC595 shift registers on 3 pins. The
  registers drive the 16 mux select lines and the L298N's IN1/IN2.
- The trimmers are gone. AD620 gain is fixed by a 1 kΩ resistor (50.4
  nominal, to be measured) and the reference is a fixed 10k/10k divider
  into the LM358 buffer. Calibration reduces to measuring the gain.
- The L298N is the bare chip rather than a driver module, and the
  ADS1115 breakout plugs into a socket.

Schematic, renders, gerbers, design-rule and ERC reports, and a list of
review notes to read before ordering are in
[hardware/README.md](../hardware/README.md).

---

Next: [Calibration](calibration.md), putting the amplifier in range and
measuring the gain.

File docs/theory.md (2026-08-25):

# Theory

The instrument measures the electrical resistivity of the ground. All of
it reduces to Ohm's law plus one geometric conversion.

## Ohm's law, applied through the ground

Inject a known current `I` into the earth through two outer electrodes.
That current creates a potential field in the soil. Measure the potential
difference `V` it produces across two inner electrodes, and

```
R = V / I
```

is a resistance in ohms, measured the same way a multimeter measures a
resistor, except the "resistor" is the ground between the electrodes. In
the validated field reading, `I` was measured across a 1 kΩ shunt
(1.24 mA) and `V` came from the instrumentation amplifier (28.5 mV),
giving R = 22.98 Ω.

## The Wenner array and the geometric factor

Four electrodes in a line, equally spaced by `a`:

```
C1 ---- P1 ---- P2 ---- C2
    a       a       a
```

Current flows between the outer pair (C1, C2). Potential is measured
across the inner pair (P1, P2). The measured R depends on the electrode
geometry as well as on the ground, so it gets converted to an apparent
resistivity:

```
rho_a = 2 * pi * a * R
```

The geometric factor 2πa converts a circuit measurement (ohms) into a
material property (ohm-metres). For the field reading:
2π x 0.5 m x 22.98 Ω = 72.2 Ω·m.

## Why the polarity alternates

Steady DC polarises the electrodes: ions pile up at the metal-soil
interface and build an opposing voltage. The earth also carries its own
self-potential from groundwater flow and electrochemistry. Both drift
more than the signal is worth. The fix is to alternate the injection
polarity and difference the two half cycles:

```
V(+) =  V_signal + V_offset
V(-) = -V_signal + V_offset

V(+) - V(-) = 2 * V_signal
```

Any steady offset (amplifier offset, mid-rail error, self-potential)
cancels exactly, while the real signal flips sign with the current, so it
survives and doubles. An L298N H-bridge does the flipping here, at about
150 ms per half cycle.

## Why stacking works

Averaging N repeated cycles knocks random noise down by roughly sqrt(N).
Measured effect on this build: bench readings went from about 0.2 Ω of
wander to stable in the second decimal place at N = 20. At ~300 ms per
full cycle a stacked measurement takes about six seconds.

## Depth of investigation

A Wenner array senses to a depth of roughly a/2, so wider spacing images
deeper.

- One spacing gives one number: the apparent resistivity down to about
  a/2. This is what the instrument has demonstrably produced.
- Multiple spacings about the same centre (a sounding) give a 1D depth
  profile.
- A 2D section needs many electrodes and automated switching, which is
  what the 16 channel multiplexing is for. That part is only partially
  done: 12 of 16 channels work and no 2D survey has been run yet.

---

Next: [Hardware](hardware.md), the circuit that implements this and the
five design constraints that were learned the hard way.

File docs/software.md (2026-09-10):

# Software guide

How to install the toolchain, put firmware on the board, take a
measurement, capture a survey to a file, and invert it. The per-sketch
READMEs in [firmware/](../firmware/) say what each sketch verifies and
what its failure looks like; this page is the end-to-end walkthrough.

## What runs where

| Build | Board | Firmware |
|---|---|---|
| Breadboard (the validated build) | Arduino Mega 2560 | sketches 00 through 06, in order |
| Custom PCB | Arduino Nano | sketch 00, then 07 (one sketch, serial commands) |

The analysis script runs on a laptop in Python, after a survey.

## Toolchain

### Arduino IDE

1. Install Arduino IDE 2.x from arduino.cc. The AVR board package (Mega,
   Nano) comes with it.
2. Library Manager (books icon in the left sidebar): search
   "Adafruit ADS1X15", install, and accept the prompt to also install
   Adafruit BusIO. Sketches 00, 02 and 03 need no libraries at all.
3. Tools > Board: "Arduino Mega or Mega 2560" for the breadboard,
   "Arduino Nano" for the PCB. For a Nano clone also set
   Tools > Processor to "ATmega328P (Old Bootloader)". If an upload fails
   with "programmer is not responding", try the other bootloader option.
4. Tools > Port: the board's serial port. macOS: `/dev/cu.usbserial-*` or
   `/dev/cu.usbmodem*`. Linux: `/dev/ttyUSB0` or `/dev/ttyACM0`. Windows:
   `COMn`. Clones with a CH340 USB chip may need the CH340 driver on
   Windows and older macOS.
5. File > Open the sketch's `.ino`, then the upload arrow.

If the IDE refuses a sketch folder whose name starts with a digit, rename
the folder and the `.ino` together (for example `s05_single_measurement`)
and keep the number.

### arduino-cli

The same thing from a terminal. These are the commands the sketches in
this repo were compile-tested with; substitute your port.

```
arduino-cli core install arduino:avr
arduino-cli lib install "Adafruit ADS1X15"

# breadboard build, Mega
arduino-cli compile --fqbn arduino:avr:mega firmware/05_single_measurement
arduino-cli upload  --fqbn arduino:avr:mega -p /dev/cu.usbserial-1420 firmware/05_single_measurement

# PCB, Nano clone with the old bootloader
arduino-cli compile --fqbn arduino:avr:nano:cpu=atmega328old firmware/07_pcb_console
arduino-cli upload  --fqbn arduino:avr:nano:cpu=atmega328old -p /dev/cu.usbserial-1420 firmware/07_pcb_console

arduino-cli monitor -p /dev/cu.usbserial-1420 -c baudrate=9600
```

### Serial monitor

9600 baud, everywhere. Commands are single characters, so the line-ending
setting does not matter. Opening the port resets the board; wait for the
banner before typing. Any terminal works: the IDE's Serial Monitor,
`arduino-cli monitor`, or `screen /dev/cu.usbserial-1420 9600` (quit with
Ctrl-A then K).

## Bring-up walkthrough, breadboard

In order. Do not wire the next stage until the current one passes. Each
step: what must be wired, what to type, what you should see, and where to
look if you do not.

**00, I2C scanner.** Wired: Mega, ADS1115 breakout, SDA (20), SCL (21),
5 V, GND. Nothing to type. Expect `Device found at 0x48` every five
seconds. If nothing is found: power at the breakout, SDA/SCL, and the
header solder joints, in that order.

**01, raw ADC.** Wired: as above. Nothing to type; it prints A0, A1 and
A2-A3 twice a second. Put the 2.5 V mid-rail on A0 and check the printed
volts against a multimeter on the same node. Expect agreement within a
few millivolts. A2-A3 near zero with current flowing means the shunt
sense wires are off.

**02, DC hold.** Wired: add the L298N, its supply, the shunt, and the
bench chain. Type `+`, `-`, or `p`. The bridge holds that state so a
multimeter can read it (a multimeter cannot follow the 150 ms square wave
the real measurement uses). Trace the voltage along the injection path
and find where it stops. Measure the actual voltage across OUT1-OUT2 at
your working current; it was 3.8 V, not 5 V, on this build.

**03, mux scan.** Wired: add the four muxes and their 16 select lines.
Nothing to type; it steps all four muxes through channels 0-15, two
seconds each, announcing the channel. Continuity-beep from each mux's
common pin to the matching electrode header. Write down every channel
that fails; they go in `CH[]` later. If all channels look the same at the
ADC, measure at the mux common pin, not through the amplifier.

**04, amplifier tuning.** Wired: add the AD620, the LM358 reference, and
the trimmers; set the `*_CHANNEL` constants to your bench wiring. Nothing
to type; it prints the forward and reverse half-cycle voltages
continuously. Follow [calibration.md](calibration.md): offset first with
no current, then gain, then offset again. Healthy looks like

```
FWD 3.5483 V   REV 0.8205 V   diff 2.7278 V   I 0.182 mA
```

Both halves near 3.6 V means saturated; fix the offset, not the gain.

**05, single measurement.** Wired: everything, with the 100 Ω reference
in the bench chain. Set `AMP_GAIN` to your measured gain. Type `m`.
Expect twenty cycle lines and then a summary; on this build the numbers
were

```
cycle 20/20  V+ 3.548  V- 0.821  I 0.1818 mA
---
V(P1-P2) = 17.9 mV
I        = 0.1818 mA
R        = 98.56 ohm
```

A negative R means the amp is railed in one polarity. A result that
changes by tenths of an ohm between runs means something upstream is
marginal.

**06, Wenner survey.** Wired: the electrode line, via the working
channels in `CH[]`. Type `s` after the port has settled. It prints a
complete pyGIMLi data file and nothing else, then parks the bridge. See
"Capturing a survey" below before you type `s`.

## Bring-up walkthrough, PCB

Sketch 00 first, unchanged. Then sketch 07 and its commands, in this
order: `r` (ADC reads), `+` `-` `p` (bridge switches, confirm at the
L298N pins with a multimeter), `c N` (mux continuity, terminal E N), `t`
(amplifier in range on the bench chain), `m` (known resistor), `w`
(survey). The [07 README](../firmware/07_pcb_console/README.md) has the
command table and the order in which to fit the chips.

## Configuring the firmware

Everything adjustable is a `const` near the top of each sketch.

| Constant | Where | Meaning | Change it when |
|---|---|---|---|
| `AMP_GAIN` | 05, 06, 07 | measured amplifier gain | after every calibration; 76 on the breadboard build, 50.4 nominal on the PCB |
| `SHUNT_OHMS` | 04-07 | shunt resistance | measure the actual resistor and use that |
| `N_STACK` | 05-07 | polarity cycles averaged per measurement | 20 gives second-decimal stability; more is slower, not much better |
| `SETTLE_MS` | 04-07 | wait after each polarity flip before reading | leave at 100 unless the amp output has not settled (check with `t`) |
| `ELECTRODE_SPACING` | 06, 07 | metres between adjacent rods | your line |
| `CH[]` | 06, 07 | electrode position to mux channel | after the mux scan finds dead channels |
| `*_CHANNEL` | 04, 05 | which mux channel each bench node is on | your bench wiring |
| Pin constants | all | Mega or Nano pins | never, unless you rewire |

## Taking a field measurement

1. Follow [field-procedure.md](field-procedure.md) for the line, the
   contact check, and power-up order.
2. Sketch 05 (or 07 with `x` to pick channels): type `m`, wait about six
   seconds.
3. Write down I, V(P1-P2) and R from the summary, plus spacing, soil, and
   moisture, in the format in [data/README.md](../data/README.md). Record
   the raw values, not just the final resistivity.
4. Apparent resistivity is 2πa·R. For the validated reading:
   2π x 0.5 m x 22.98 Ω = 72.2 Ω·m.
5. Take the number promptly. Readings drift upward within minutes as the
   steel electrodes polarise.

## Capturing a survey to a file

The survey sketches print the data file over serial. Getting it into a
file:

- **Sketch 06** prints only the data, so any capture of the serial
  output is the file. Open the capture first, then type `s`.
- **Sketch 07** also prints its banner and command replies. Capture
  everything, then run `python analysis/clean_capture.py capture.txt
  survey.dat`, which keeps just the data block.

Ways to capture:

```
# arduino-cli: everything the board prints goes to the file, typing still works
arduino-cli monitor -p /dev/cu.usbserial-1420 -c baudrate=9600 | tee capture.txt

# screen (macOS, Linux)
screen -L -Logfile capture.txt /dev/cu.usbserial-1420 9600
```

In the Arduino IDE, select all the text in the Serial Monitor output pane
after the survey ends and paste it into a file. On Windows, PuTTY's
Session > Logging > "Printable output" does the same job.

A survey over 12 electrodes takes about 18 x 6 s, roughly two minutes;
over 16 electrodes (sketch 07 default) about 35 x 6 s.

## Running the inversion

```
conda create -n ert -c gimli -c conda-forge pygimli
conda activate ert
cd analysis
python invert_pygimli.py survey.dat        # lam = 20
python invert_pygimli.py survey.dat 50     # smoother
```

A window opens with the inverted resistivity section; close it to exit.
What to check before believing it: every `rhoa` in the file is positive
and in a sensible range (tens of Ω·m for the clay this was built on);
electrode numbers in the data rows are 1-indexed; and the picture does
not change character when you double `lam`. With 18-35 data points the
regularisation is doing most of the work. See
[analysis/README.md](../analysis/README.md).

## Troubleshooting

| Symptom | Look at |
|---|---|
| `ADS1115 not found` at boot | sketch 00; power, SDA/SCL, solder |
| Upload fails, "programmer is not responding" | wrong board or bootloader selection; wrong port; CH340 driver |
| Sketch folder rejected by the IDE | rename folder and `.ino` together, keep the number |
| Both half-cycles the same voltage | amp saturated or input floating; [failure log](failure-log.md), 3.62 V entry |
| Negative resistance | amp railed in one polarity; recentre offset (breadboard) or reduce injection voltage (PCB) |
| R stable but wrong | asymmetric chain, or nominal injection voltage assumed; [calibration.md](calibration.md) |
| Multimeter says no current while measuring | it cannot track the square wave; sketch 02 or `+`/`-` |
| Some electrodes never conduct | mux scan; edit `CH[]` |
| Survey capture has junk before the data | `analysis/clean_capture.py` |
| Inversion shows structure that vanishes at higher `lam` | it was noise; keep `lam` high |

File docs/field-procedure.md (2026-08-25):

# Field procedure

How the validated field reading was taken, written as a repeatable
procedure. This is a single point Wenner measurement using firmware
sketch [05_single_measurement](../firmware/05_single_measurement/).

## Equipment

- The instrument, a 12 V injection supply or battery, and a laptop
- Four stainless steel electrode rods and a hammer
- Tape measure
- Multimeter, for the contact check
- Water, for dry ground

## Procedure

1. **Lay out the line.** Four electrodes equally spaced by `a`, in the
   order C1, P1, P2, C2. The validated reading used a = 0.5 m. Drive each
   rod no deeper than about a/10 so it behaves like a point electrode.

2. **Check electrode contact.** Multimeter between adjacent rods. In
   moist Georgia clay this build measured 40-80 kΩ. That sounds
   disqualifying and is not; it is the reason the instrument uses four
   electrodes in the first place (see the [README](../README.md)). At the
   current pair, contact resistance only limits how much current flows,
   and the current is measured across the shunt rather than assumed. At
   the potential pair no current flows, so its contact resistance drops
   no voltage. If the reading is far above this range, wet the soil
   around the rods.

3. **Wire and power up.** C1/C2 to the outer rods, P1/P2 to the inner
   pair. Power the logic first and confirm the ADC answers (sketch 00
   takes seconds), then enable the injection supply.

4. **Measure promptly, and record everything raw.** Run sketch 05. Log
   the injected current, the measured potential, and the computed R, not
   just the final resistivity, so the result can be recomputed later. The
   validated reading in full:

   ```
   # Wenner array, a = 0.5 m, Georgia clay soil, moist
   # I = 1.24 mA, V(P1-P2) = 28.5 mV
   # R = 22.98 Ω, ρ = 2πaR = 72.20 Ω·m
   ```

5. **Between readings the firmware parks the bridge** (both H-bridge
   inputs low). Do not leave DC flowing while setting up the next
   reading. See the drift note below.

## The known limitation: polarisation drift

Readings drifted from 71 to 90 Ω·m over several minutes as the steel
potential electrodes polarised. This bounds how long a survey can run:
past that window, later measurements read systematically higher for
electrochemical rather than geological reasons, and the drift shows up as
a false gradient in the data.

The standard fix is non-polarising electrodes for the potential pair: a
copper rod in saturated copper sulphate solution inside a porous pot.
They are cheap to build, and they are the hardware change this project
needs before any multi-minute survey is credible.

---

Next: [Firmware](../firmware/README.md), bring-up in seven sketches, run
in order.

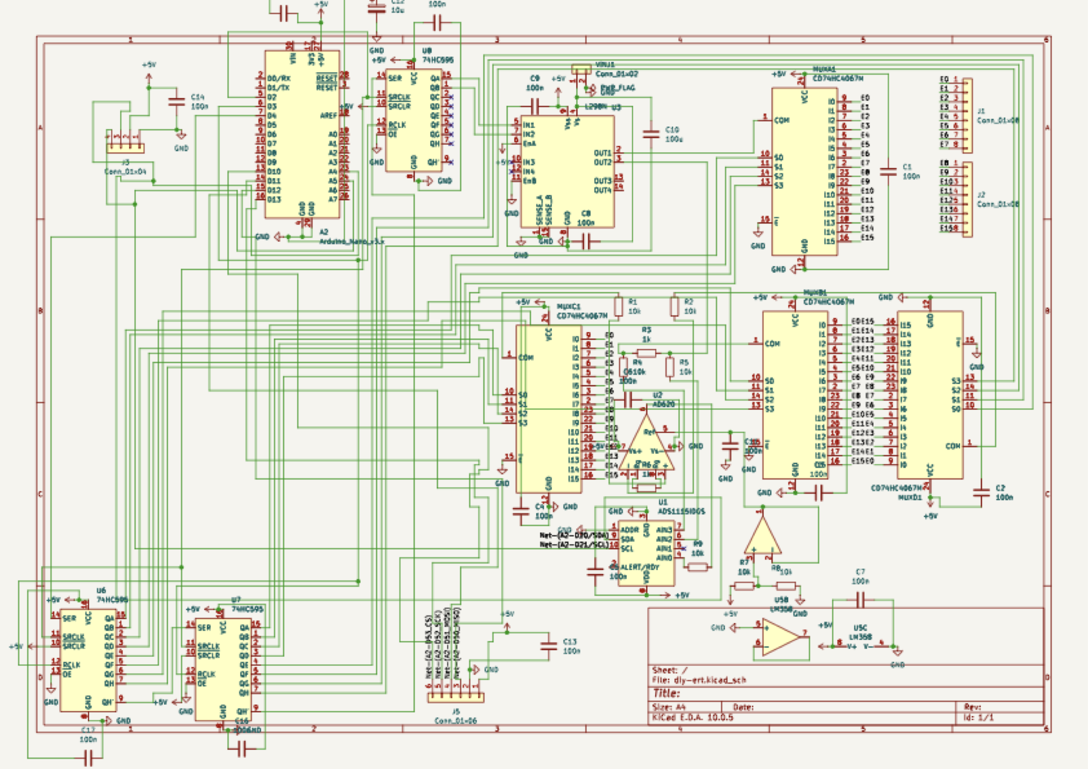
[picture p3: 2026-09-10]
hardware/images/schematic.png

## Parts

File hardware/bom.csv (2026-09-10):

Reference | Value | Footprint | QUANTITY
A2 | Arduino_Nano_v3.x | Module:Arduino_Nano | 1
C1-C9,C11,C13-C18 | 100n | Capacitor_THT:C_Disc_D5.0mm_W2.5mm_P5.00mm | 16
C10 | 100u | Capacitor_THT:CP_Radial_D5.0mm_P2.50mm | 1
C12 | 10u | Capacitor_THT:CP_Radial_D5.0mm_P2.50mm | 1
J1,J2 | Conn_01x08 | TerminalBlock_Phoenix:TerminalBlock_Phoenix_MPT-0,5-8-2.54_1x08_P2.54mm_Horizontal | 2
J3 | Conn_01x04 | Connector_PinSocket_2.54mm:PinSocket_1x04_P2.54mm_Vertical | 1
J5 | Conn_01x06 | Connector_PinSocket_2.54mm:PinSocket_1x06_P2.54mm_Vertical | 1
MUXA1,MUXB1,MUXC1,MUXD1 | CD74HC4067M | Package_DIP:DIP-24_W15.24mm | 4
R1,R2,R4,R5,R7-R9 | 10k | Resistor_THT:R_Axial_DIN0207_L6.3mm_D2.5mm_P10.16mm_Horizontal | 7
R3,R6 | 1k | Resistor_THT:R_Axial_DIN0207_L6.3mm_D2.5mm_P10.16mm_Horizontal | 2
U1 | ADS1115IDGS | Connector_PinSocket_2.54mm:PinSocket_1x10_P2.54mm_Vertical | 1
U2 | AD620 | Package_DIP:DIP-8_W7.62mm | 1
U3 | L298N | Package_TO_SOT_THT:TO-220-15_P2.54x5.08mm_StaggerOdd_Lead4.58mm_Vertical | 1
U5 | LM358 | Package_DIP:DIP-8_W7.62mm | 1
U6-U8 | 74HC595 | Package_DIP:DIP-16_W7.62mm_Socket | 3
VINJ1 | Conn_01x02 | TerminalBlock_Phoenix:TerminalBlock_Phoenix_MPT-0,5-2-2.54_1x02_P2.54mm_Horizontal | 1

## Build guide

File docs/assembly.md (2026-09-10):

# Build guide

The physical side: what goes where, in what order, and every connection,
so the instrument can be rebuilt without the original in front of you.

Two versions exist. The breadboard build is the one every result in this
repo came from. The PCB in [hardware/](../hardware/) is designed and
DRC-clean but has not been built yet. The connection list below is the
same circuit either way; where the breadboard differs, the table says
so.

## Power

Two supplies, one ground.

| Rail | Source | Feeds |
|---|---|---|
| 5 V logic | the Arduino's USB (the Nano's 5V pin on the PCB, the Mega's on the breadboard) | muxes, shift registers, AD620, LM358, ADS1115, L298N logic (Vss and EnA) |
| Injection | a separate supply into VINJ1 (PCB) or the L298N Vs input (breadboard) | the L298N bridge only |
| Ground | common to both | everything; the L298N SENSE pins, mux enable pins, 595 output-enable pins and the ADS1115 ADDR pin all sit on it |

Power-up order, every time: logic first, confirm the ADC answers
(sketch 00), then the injection supply. Reverse it when shutting down.
With 12 V injection the resistor-chain nodes reached 6.3 V, above the
ADC's 5.3 V absolute maximum; the 10 kΩ series resistors exist for that
reason and must be in place before the injection supply is ever
connected ([hardware.md](hardware.md), constraint 1).

## Physical arrangement

The PCB floorplan, which is also the layout to copy on a breadboard:
logic on the left, the amplifier and ADC in the top-right, the injection
parts in the bottom-right, the muxes in the middle with the electrode
terminals directly below them.

```
 +------------------------------------------------------------------+
 | [Nano / Mega]                 C12   R6  [U2 AD620]    [U1        |
 |                                         [U5 LM358]     ADS1115]  |
 |          [U8 595]*     R1 R2                                     |
 | [U7 595]*    [U6 595]*          R7 R8 R9              [J3 I2C]   |
 |                                                       [J5 SPI]   |
 | [MUX A  (C1)]         [MUX B  (C2)]                              |
 |                                             R5  C10   [VINJ1]    |
 | [MUX C  (P1)]         [MUX D  (P2)]         R3        [U3 L298N] |
 |                                             R4                   |
 |   [J1  E0..E7]          [J2  E8..E15]                            |
 +------------------------------------------------------------------+
   * PCB only. The breadboard drives the mux select lines and the
     bridge directly from Mega pins.
```

The point of the arrangement is distance: the millivolt path (terminals,
mux C and D, R1/R2, AD620) stays on the far side of the board from the
L298N and its supply.

## Connection list

Taken from the KiCad netlist of the PCB. Pin numbers are the DIP or
module pins.

### Electrode bus

Each electrode terminal goes to the same-numbered input on all four
muxes.

| Electrode | Terminal | Mux input | Mux pin |
|---|---|---|---|
| E0 | J1-1 | I0 | 9 |
| E1 | J1-2 | I1 | 8 |
| E2 | J1-3 | I2 | 7 |
| E3 | J1-4 | I3 | 6 |
| E4 | J1-5 | I4 | 5 |
| E5 | J1-6 | I5 | 4 |
| E6 | J1-7 | I6 | 3 |
| E7 | J1-8 | I7 | 2 |
| E8 | J2-1 | I8 | 23 |
| E9 | J2-2 | I9 | 22 |
| E10 | J2-3 | I10 | 21 |
| E11 | J2-4 | I11 | 20 |
| E12 | J2-5 | I12 | 19 |
| E13 | J2-6 | I13 | 18 |
| E14 | J2-7 | I14 | 17 |
| E15 | J2-8 | I15 | 16 |

### Multiplexers, CD74HC4067 (DIP-24)

Common to all four: pin 24 VCC to 5 V, pin 12 GND, pin 15 (enable,
active low) to GND. Select inputs are S0 = pin 10, S1 = pin 11,
S2 = pin 14, S3 = pin 13. Pin 1 is the common.

| Mux | Role | Common (pin 1) goes to | S0-S3 from, PCB | S0-S3 from, breadboard (Mega) |
|---|---|---|---|---|
| A | C1 | L298N OUT1 | U6 QA, QB, QC, QD (pins 15, 1, 2, 3) | 22, 24, 26, 28 |
| B | C2 | shunt R3, and R4 to ADS1115 A3 | U6 QE, QF, QG, QH (pins 4, 5, 6, 7) | 30, 32, 34, 36 |
| C | P1 | R1 (10 kΩ) to AD620 +IN | U7 QA, QB, QC, QD | 38, 40, 42, 44 |
| D | P2 | R2 (10 kΩ) to AD620 -IN | U7 QE, QF, QG, QH | 46, 48, 50, 52 |

### Shift registers, 74HC595 (DIP-16), PCB only

| Pin | U6 | U7 | U8 |
|---|---|---|---|
| 14 SER | Nano D4 | U6 pin 9 (QH') | U7 pin 9 (QH') |
| 11 SRCLK | Nano D2 | Nano D2 | Nano D2 |
| 12 RCLK | Nano D3 | Nano D3 | Nano D3 |
| 13 OE (active low) | GND | GND | GND |
| 10 SRCLR (active low) | 5 V | 5 V | 5 V |
| 16 VCC, 8 GND | 5 V, GND | 5 V, GND | 5 V, GND |
| 15, 1, 2, 3 (QA-QD) | MUX A S0-S3 | MUX C S0-S3 | L298N IN1 (QA), IN2 (QB); QC, QD unused |
| 4, 5, 6, 7 (QE-QH) | MUX B S0-S3 | MUX D S0-S3 | unused |
| 9 QH' | U7 SER | U8 SER | unused |

### Injection, L298N (Multiwatt-15)

| Pin | Name | Goes to |
|---|---|---|
| 1 | SENSE A | GND |
| 2 | OUT1 | MUX A common |
| 3 | OUT2 | shunt R3 (1 kΩ), and R5 (10 kΩ) to ADS1115 A2 |
| 4 | Vs | VINJ1 +, with C10 (100 µF) and C8 (100 nF) to GND |
| 5 | IN1 | U8 QA (PCB); Mega pin 6 (breadboard) |
| 6 | EnA | 5 V |
| 7 | IN2 | U8 QB (PCB); Mega pin 7 (breadboard) |
| 8 | GND | GND |
| 9 | Vss | 5 V (logic supply) |
| 10, 12 | IN3, IN4 | not connected |
| 11 | EnB | GND |
| 13, 14 | OUT3, OUT4 | not connected |
| 15 | SENSE B | GND |

The shunt R3 sits between OUT2 and MUX B's common. The ADS1115 reads
across it: A2 on the OUT2 side through R5, A3 on the mux side through
R4. On the breadboard the L298N is a driver module; keep its ENA jumper
fitted and leave bridge B unused.

### Potential sense, AD620 (DIP-8)

| Pin | Name | Goes to |
|---|---|---|
| 1, 8 | RG | R6, 1 kΩ (PCB, gain 50.4 nominal); 10 kΩ trimmer (breadboard, measured 76) |
| 2 | -IN | R2 (10 kΩ) from MUX D common |
| 3 | +IN | R1 (10 kΩ) from MUX C common |
| 4 | -VS | GND |
| 5 | REF | LM358 pin 1, with C11 (100 nF) to GND |
| 6 | OUT | R9 (10 kΩ) to ADS1115 A0 |
| 7 | +VS | 5 V |

### Reference, LM358 (DIP-8)

| Pin | Name | Goes to |
|---|---|---|
| 1 | OUT A | AD620 REF (the 2.5 V reference) |
| 2 | -IN A | pin 1 (unity-gain follower) |
| 3 | +IN A | junction of R7 (10 kΩ to 5 V) and R8 (10 kΩ to GND); the breadboard has the offset trimmer here |
| 4 | V- | GND |
| 5 | +IN B | GND |
| 6 | -IN B | pin 7 |
| 7 | OUT B | pin 6 (unused half, parked as a follower) |
| 8 | V+ | 5 V |

### ADC, ADS1115 breakout

| Module pin | Goes to |
|---|---|
| VDD | 5 V |
| GND | GND |
| SCL | Nano A5 (Mega 21), and J3-4 |
| SDA | Nano A4 (Mega 20), and J3-3 |
| ADDR | GND, giving address 0x48 |
| ALRT | not connected |
| A0 | R9 (10 kΩ) from AD620 OUT |
| A1 | not connected |
| A2 | R5 (10 kΩ) from L298N OUT2 |
| A3 | R4 (10 kΩ) from MUX B common |

On the PCB the breakout plugs into the 10-pin socket U1, whose pin order
follows the ADS1115 chip rather than the breakout header. Read review
note 1 in [hardware/README.md](../hardware/README.md) before fitting it.

### Decoupling

100 nF between VCC and GND at every IC (C1-C9, C13-C18). C12, 10 µF, on
the 5 V rail by the Nano. C10, 100 µF, and C8, 100 nF, on the injection
supply at the L298N. C11, 100 nF, on the reference node.

### Headers, PCB only

| Ref | Pins |
|---|---|
| J3 | GND, 5 V, SDA, SCL (I2C, for a display or a second sensor) |
| J5 | 5 V, GND, MISO (D12), MOSI (D11), SCK (D13), CS (D10) (SPI, unused by the firmware; an SD card logger is the obvious use) |
| VINJ1 | injection supply +, GND |

## Assembly order, PCB

1. Bare board: with a multimeter, 5 V to GND must be open circuit, and
   VINJ1 + to GND and to 5 V both open.
2. Lowest parts first: resistors, then DIP sockets (leave the chips out),
   ceramic capacitors, the pin sockets U1, J3 and J5, the Nano's two
   header rows, the electrolytics (C12 positive to 5 V; C10 positive to
   the VINJ1 side, see review note 4), the screw terminals, and the L298N
   last, standing upright at the board edge. At a milliampere of
   injection current it needs no heatsink.
3. Power over USB with no chips fitted. Confirm 5 V at the VCC pin of
   every socket and 0 V at every GND pin. Do not skip this; a solder
   bridge found now costs nothing, found later it costs a chip.
4. Fit chips in bring-up order and test each stage before the next, as in
   [software.md](software.md): Nano and ADS1115 breakout (sketch 00);
   shift registers and L298N with the injection supply still off (sketch
   07, `+` `-` `p`, meter on the L298N inputs); muxes (`c N`, continuity
   from each mux common pin to terminal E N); AD620 and LM358 (`t` with
   the bench chain); then `m` on the 100 Ω reference. Only then connect
   the injection supply to VINJ1.

## Assembly order, breadboard

The same idea with jumper wires. What the failure log says about the
breadboard build, condensed:

- Solder the header pins on every breakout. Press-fit pins pass a visual
  check and fail electrically.
- Continuity-test jumpers before use. One failed inside its insulation
  and cost hours.
- Mux channels 0, 7, 11 and 12 on the original build were dead from
  breadboard contact faults, not chip faults. Seat the DIP-24 muxes
  firmly and scan them (sketch 03) before trusting any channel.
- Put the injection wiring on the opposite side of the board from the
  amplifier, and keep the P1/P2 wires short.
- Fit the 10 kΩ series resistors on the ADC inputs before the injection
  supply is ever connected. Four ADS1115s died without them.
- Build one subsystem at a time, in the firmware order, and verify each
  against a multimeter before adding the next.

## Electrode line

Sixteen rods (or however many channels you use), equally spaced by `a`,
numbered along the line, each on its own conductor to terminal E0-E15 in
order. Drive rods no deeper than about a/10. Run the current-pair and
potential-pair conductors as separate bundles rather than one ribbon, so
the switching edges on the current wires do not couple into the
millivolt signal. Steel rods polarise within minutes; for anything longer
than a single reading, the potential pair should be non-polarising
copper-sulphate electrodes ([field-procedure.md](field-procedure.md)).

## Parts not on the PCB

| Part | Qty | Notes |
|---|---|---|
| Stainless steel rods, 30-50 cm | 4-16 | threaded rod or tent stakes |
| Wire to the rods | 16 conductors | plus crocodile clips or ring terminals |
| 12 V supply or battery | 1 | injection; a bench supply at 5 V was used for the bench validation |
| USB cable | 1 | logic power and serial |
| Multimeter | 1 | every step of the bring-up depends on it |
| Breadboard build only: 10 kΩ multi-turn trimmers | 2 | gain and offset |
| Breadboard build only: breadboards and jumpers | 3-4 | |

## Before first power-up

- [ ] 5 V to GND open circuit
- [ ] Injection + to GND open, and not connected to 5 V anywhere
- [ ] Every chip's notch matches the socket and silkscreen
- [ ] Electrolytic polarity
- [ ] 10 kΩ resistors in place on every ADC input
- [ ] ADS1115 breakout header order matches the socket (PCB)
- [ ] Breakout headers soldered (breadboard)
- [ ] Jumpers continuity-tested (breadboard)
- [ ] Injection supply disconnected until sketch 00 passes

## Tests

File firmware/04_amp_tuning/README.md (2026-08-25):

# 04: Live amplifier tuning

**Verifies:** the AD620 operates inside its input range and its output
responds to both injection polarities.

**How to use:** wire the symmetric bench chain
([docs/calibration.md](../../docs/calibration.md)), set the `*_CHANNEL`
constants to the mux channels your chain is wired to, and watch the two
half cycle voltages while adjusting the trimmers. Follow the calibration
order: offset first, with no current flowing, then gain, then re-check
offset.

**Healthy:** the two polarities land near 1.5 V and 3.5 V, clearly
separated, no clipping against either rail, and the current column shows
a stable, plausible value.

**Failure signature:** both halves near 3.6 V means the amplifier is
saturated. That is an offset problem, not a gain problem; the gain
trimmer does nothing while the output is pinned. A floating input
produces the same 3.62 V on every mux channel
([docs/failure-log.md](../../docs/failure-log.md)).

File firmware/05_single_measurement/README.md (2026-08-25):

# 05: Single measurement

**Verifies:** the entire signal chain end to end, against a known
resistor. This is the sketch that validates the instrument.

**How to use:** wire a known resistor (100 Ω) as the target inside the
symmetric bench chain, set `AMP_GAIN` to your measured gain from
[docs/calibration.md](../../docs/calibration.md) and the `*_CHANNEL`
constants to your wiring, open the serial monitor, and send `m`.

**Expected:** about 100 Ω on a 100 Ω target. This build reported
**98.56 Ω** (1.4% error). With stacking at N = 20 the result should hold
steady in the second decimal place between runs. If you see ~0.2 Ω of
wander, something upstream is marginal; re-check the amplifier tuning
(sketch 04) before blaming noise.

**Failure signatures:**

- Negative resistance is physically impossible. The amplifier is railed
  in one polarity and producing a large fake differential. Re-centre the
  offset and reduce the gain
  ([docs/failure-log.md](../../docs/failure-log.md)).
- Plausible but wrong values that change between runs: if the code was
  modified, check that the stacking accumulators are still initialised
  to zero. Uninitialised floats contain garbage that averages into
  convincing nonsense.

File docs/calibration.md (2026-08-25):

# Calibration

The gain and offset trimmers interact, so the order below matters. Done
out of order the procedure converges slowly or not at all.

Run firmware sketch [04_amp_tuning](../firmware/04_amp_tuning/) while
doing this. It prints both half cycle voltages live.

## The bench chain

Calibration and validation both run against a known resistor inside a
symmetric chain across the bridge outputs:

```
 OUT1 --[10 kΩ]-- M --[100 Ω]-- N --[10 kΩ]-- OUT2
                  |             |
              to MUX C      to MUX D
              (P1 role)     (P2 role)
```

The equal arms keep M and N near mid-rail in both polarities, inside the
AD620's input window. This build's chain measured 20.9 kΩ end to end,
out of circuit. An asymmetric chain is the documented way to get a
stable, wrong answer (see the [failure log](failure-log.md), 144 Ω
entry).

## Procedure

1. **Offset, with no current flowing.** Tie both amplifier inputs to the
   same mid-rail node (a 10k/10k divider from 5 V). The differential
   input is then exactly zero, so whatever appears at the output is pure
   offset. Trim to 2.5 V.

   > [!NOTE]
   > Tying the inputs to ground instead does not work. 0 V common-mode is
   > outside the AD620's input range ([hardware.md](hardware.md),
   > constraint 2), and the output tells you nothing about the offset.

2. **Gain, with injection running.** Return the inputs to the sense
   nodes. Trim until the two polarities land roughly at 1.5 V and 3.5 V:
   clear separation, no clipping against either rail.

3. **Re-check offset.** The trimmers interact, so expect the offset to
   have moved. Iterate steps 1 and 2 until both hold.

4. **Compute the gain from measurement, not from theory.**

   ```
   GAIN = (V_plus - V_minus) / (differential measured directly with a multimeter)
   ```

   The trimmer's nominal setting and the AD620 gain equation are starting
   points, not answers.

## Worked example, from the actual build

| Quantity | Value | How obtained |
|---|---|---|
| Chain resistance | 20.9 kΩ | measured with multimeter, out of circuit |
| Injection voltage | 3.8 V | measured across OUT1-OUT2, not the 5 V nominal |
| V(M-N) | ±17.9 mV | measured directly, symmetric in both polarities |
| Gain | 76 | (3.5483 - 0.8205) / 0.0358 |
| **Result** | **98.56 Ω** on a 100 Ω resistor | instrument's own computation |

The symmetry of the ±17.9 mV reading was itself the diagnostic that
mattered: identical magnitude in both polarities is what confirmed both
half cycles were finally being sensed inside the amplifier's input range.
The earlier asymmetric chain produced numbers just as stable, and a 144 Ω
answer for a 100 Ω resistor, because one half cycle was measured out of
range.

The measured gain (76 for this build) goes into the `AMP_GAIN` constant
in firmware sketches 05 and 06. It belongs to this particular trimmer
setting, not to the design. Re-derive it after any change to the analog
front end.

---

Next: [Failure log](failure-log.md), every way this instrument broke.

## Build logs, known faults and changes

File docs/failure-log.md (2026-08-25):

# Failure log

The most useful document in this repository. Every entry cost real time
or real parts. Each is recorded as symptom, root cause, fix, so nobody
pays for the same lesson twice.

| Failure | Symptom | Root cause | Fix |
|---|---|---|---|
| Four dead ADS1115s | I2C device not found; pins hot to touch | Chain nodes at 6.3 V exceeding the 5.3 V absolute maximum | 10 kΩ series resistors on every line entering the ADC |
| Unsoldered breakout headers | Intermittent I2C over several days | Header pins press-fitted, not soldered | Bought a soldering station; solder every breakout |
| Amplifier always reads 3.62 V | Identical value on every mux channel | Single-supply amp with a floating input saturates regardless of gain | Ensure both amp inputs sit on real nodes; adjust offset before gain |
| Resistance reads 144 Ω instead of 100 Ω | Stable but wrong | Asymmetric chain put one sense node above the amp's input ceiling, so one half cycle was measured out of range | Symmetric chain |
| Current reads zero while bridge is driving | Shunt shows no voltage | Multimeter cannot track a 150 ms square wave; it averages toward zero | Park the bridge in DC for multimeter work (firmware sketch 02) |
| Negative resistance in survey data | Physically impossible values | Amplifier railed in one polarity, producing a huge fake differential | Re-centre offset, reduce gain |
| Hours lost to a broken wire | Bridge outputs stuck near 0 V | Jumper failed internally, no visible damage | Continuity-test wires before suspecting components |
| 4 of 16 mux channels dead | Some electrodes never conduct | Breadboard contact faults, not chip or addressing faults; the dead channel numbers (0, 7, 11, 12) share no common address bit | Lookup table maps electrode position to working channel |

Time cost, where known: the ADC failure destroyed four chips before the
root cause was found. The unsoldered headers caused intermittent faults
for several days because the pins passed visual inspection. The broken
jumper took several hours because every component upstream of it got
suspected first.

## What the failures have in common

Nearly all of them were mechanical (unsoldered headers, breadboard
contacts, a jumper broken inside its insulation) or a voltage-domain
mismatch (chain nodes above the ADC's absolute maximum, sense nodes
outside the amplifier's input window). Almost none were logic errors. The
code was rarely the problem.

The other pattern: the dangerous failures all looked fine. An unsoldered
header looks soldered. A 6.3 V node looks like a 5 V node. An amplifier
measuring out of range still prints stable, plausible numbers.

The debugging method that consistently worked was isolating one subsystem
at a time and verifying it against an independent instrument, a
multimeter or a known resistor, before adding the next subsystem on top.
That method is what the [firmware directory](../firmware/) encodes: seven
sketches, run in order, each proving a single layer.

---

Next: [Field procedure](field-procedure.md), taking the instrument
outside.

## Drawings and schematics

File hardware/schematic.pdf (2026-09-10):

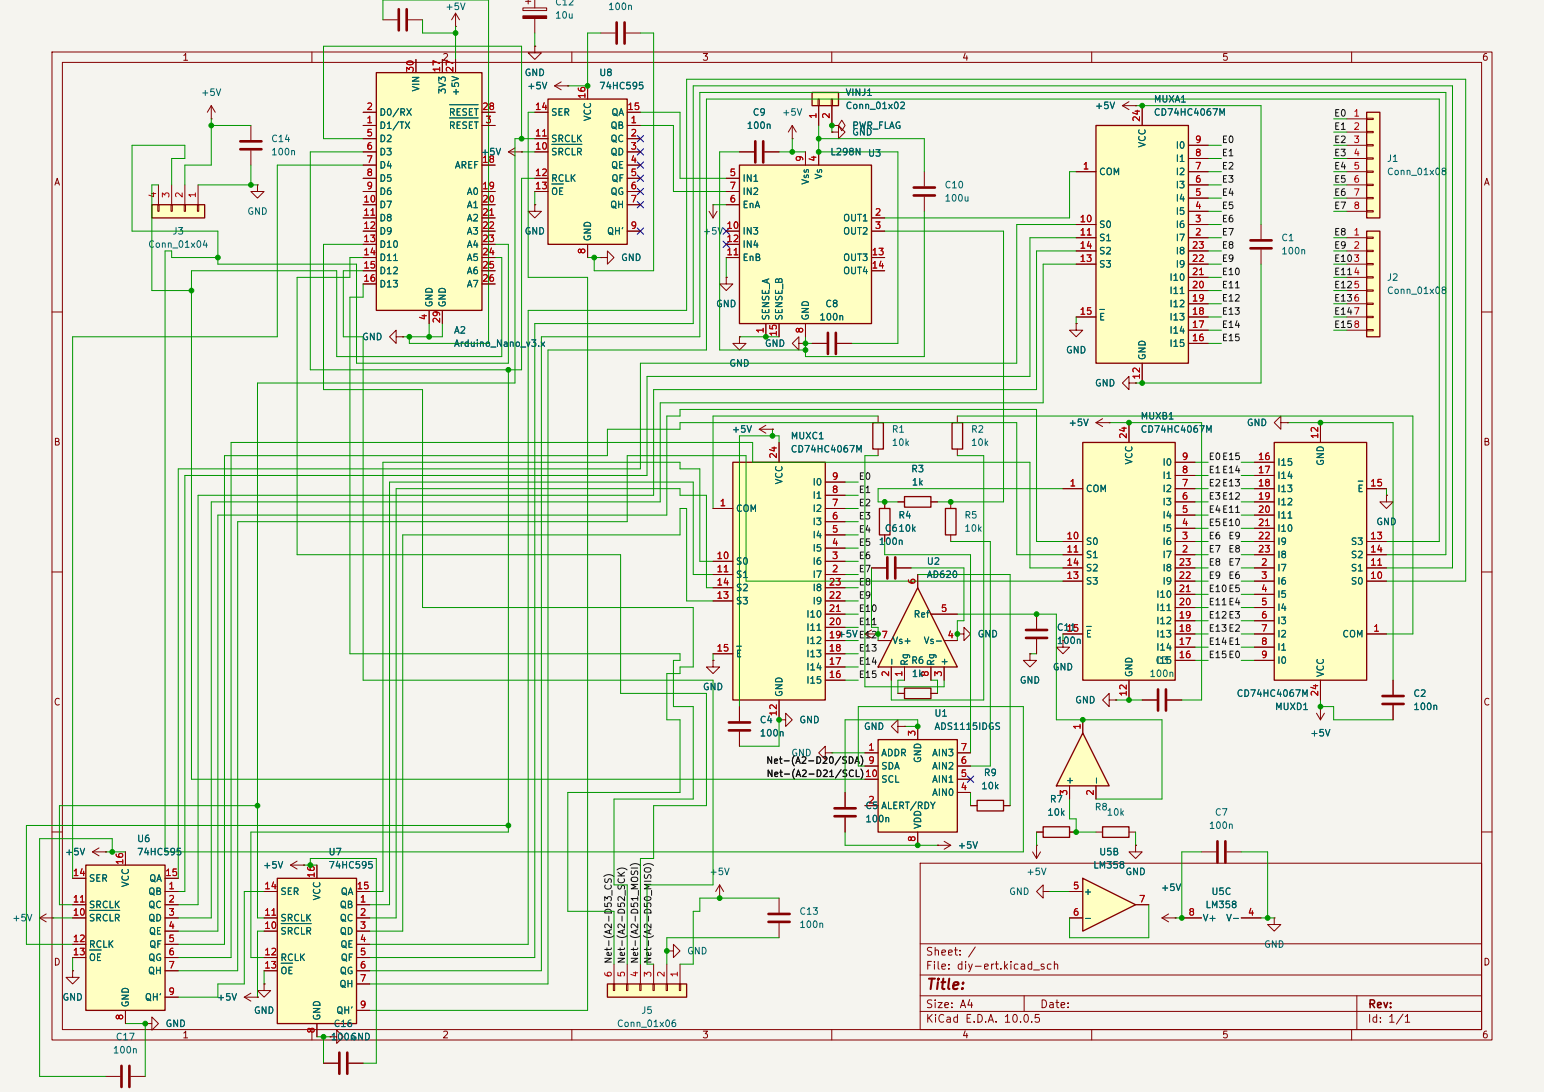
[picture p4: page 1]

SRCLR 10 SRCLK 11 RCLK 12 OE 13

Size: A4 | Rev:
KiCad E.D.A. 10.0.5 | Id: 1/1

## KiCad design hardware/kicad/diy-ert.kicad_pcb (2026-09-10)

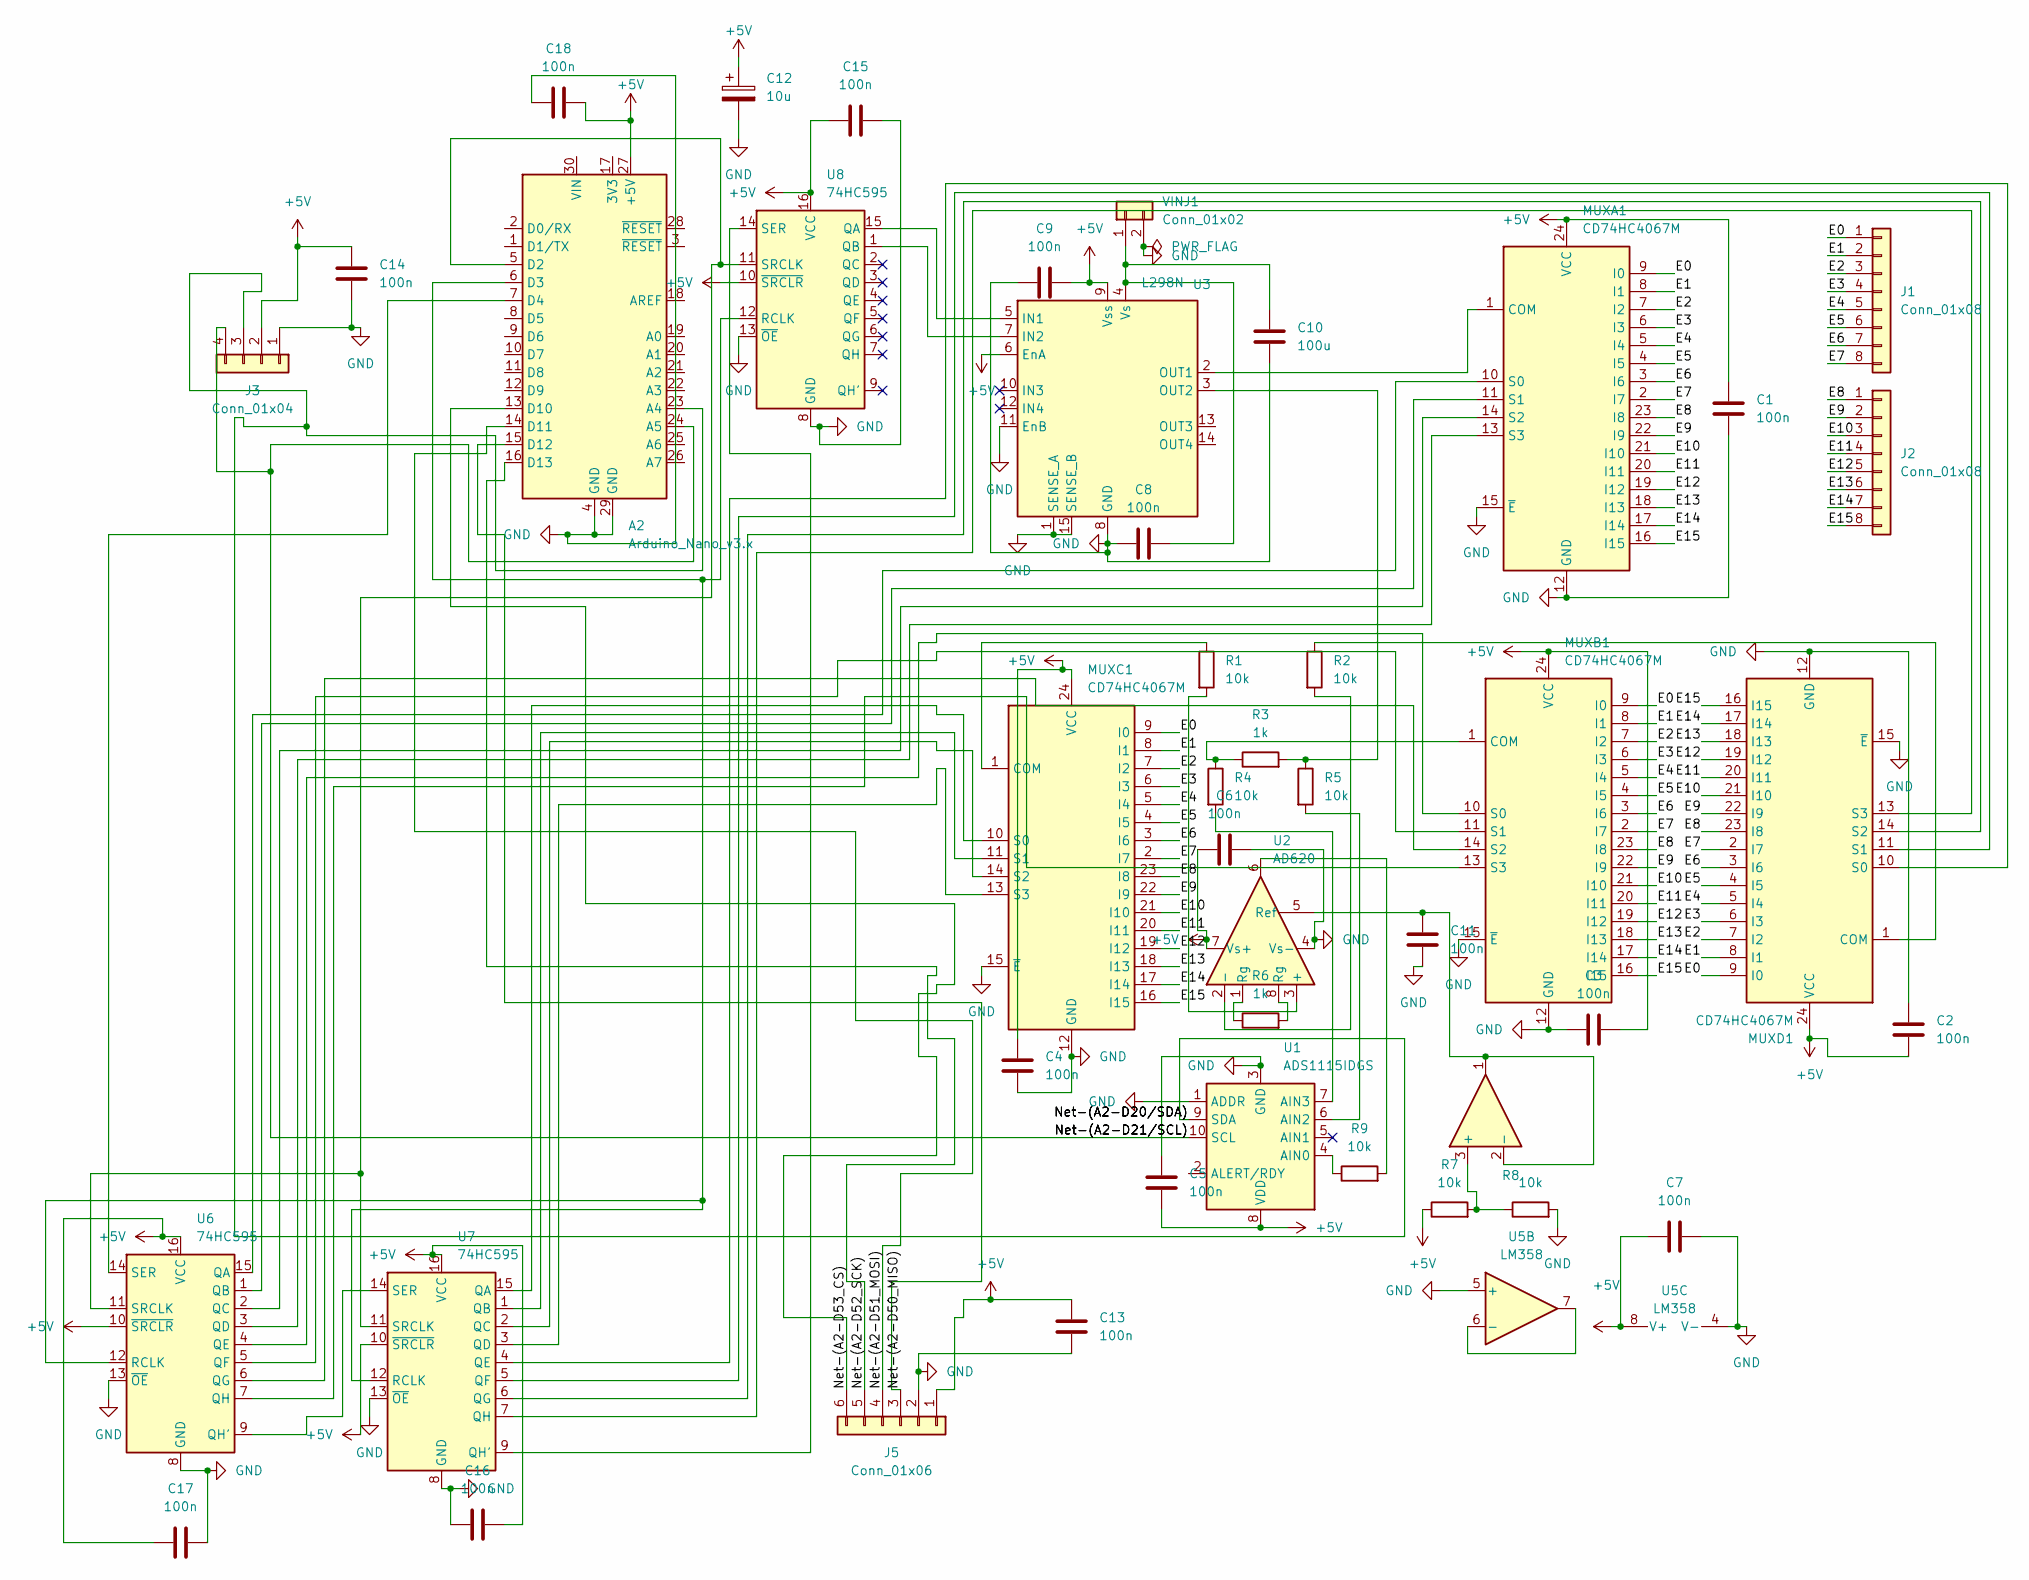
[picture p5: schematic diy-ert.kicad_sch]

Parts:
A2: Arduino_Nano_v3.x; Arduino_Nano
C1, C2, C3, C4, C5, C6, C7, C8, C9, C11, C13, C14, C15, C16, C17, C18: 100n; C_Disc_D5.0mm_W2.5mm_P5.00mm
C10: 100u; CP_Radial_D5.0mm_P2.50mm
C12: 10u; CP_Radial_D5.0mm_P2.50mm
J1, J2: Conn_01x08; TerminalBlock_Phoenix_MPT-0,5-8-2.54_1x08_P2.54mm_Horizontal
J3: Conn_01x04; PinSocket_1x04_P2.54mm_Vertical
J5: Conn_01x06; PinSocket_1x06_P2.54mm_Vertical
MUXA1: CD74HC4067M; DIP-24_W15.24mm
MUXB1: CD74HC4067M; DIP-24_W15.24mm
MUXC1: CD74HC4067M; DIP-24_W15.24mm
MUXD1: CD74HC4067M; DIP-24_W15.24mm
R1, R2, R4, R5, R7, R8, R9: 10k; R_Axial_DIN0207_L6.3mm_D2.5mm_P10.16mm_Horizontal
R3, R6: 1k; R_Axial_DIN0207_L6.3mm_D2.5mm_P10.16mm_Horizontal
U1: ADS1115IDGS; PinSocket_1x10_P2.54mm_Vertical
U2: AD620; DIP-8_W7.62mm
U3: L298N; TO-220-15_P2.54x5.08mm_StaggerOdd_Lead4.58mm_Vertical
U5: LM358; DIP-8_W7.62mm
U6, U7, U8: 74HC595; DIP-16_W7.62mm_Socket
VINJ1: Conn_01x02; TerminalBlock_Phoenix_MPT-0,5-2-2.54_1x02_P2.54mm_Horizontal

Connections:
+5V: A2.27 (+5V), C1.1, C2.2, C3.2, C4.2, C5.1, C6.2, C7.1, C9.2, C12.1, C13.1, C14.1, C15.1, C16.2, C17.2, C18.2, J3.2, J5.1, MUXA1.24 (VCC), MUXB1.24 (VCC), MUXC1.24 (VCC), MUXD1.24 (VCC), R7.1, U1.8 (VDD), U2.7 (Vs+), U3.6 (EnA), U3.9 (Vss), U5.8 (V+), U6.10 (~SRCLR), U6.16 (VCC), U7.10 (~SRCLR), U7.16 (VCC), U8.10 (~SRCLR), U8.16 (VCC)
/E0: J1.1, MUXA1.9 (I0), MUXB1.9 (I0), MUXC1.9 (I0), MUXD1.9 (I0)
/E1: J1.2, MUXA1.8 (I1), MUXB1.8 (I1), MUXC1.8 (I1), MUXD1.8 (I1)
/E2: J1.3, MUXA1.7 (I2), MUXB1.7 (I2), MUXC1.7 (I2), MUXD1.7 (I2)
/E3: J1.4, MUXA1.6 (I3), MUXB1.6 (I3), MUXC1.6 (I3), MUXD1.6 (I3)
/E4: J1.5, MUXA1.5 (I4), MUXB1.5 (I4), MUXC1.5 (I4), MUXD1.5 (I4)
/E5: J1.6, MUXA1.4 (I5), MUXB1.4 (I5), MUXC1.4 (I5), MUXD1.4 (I5)
/E6: J1.7, MUXA1.3 (I6), MUXB1.3 (I6), MUXC1.3 (I6), MUXD1.3 (I6)
/E7: J1.8, MUXA1.2 (I7), MUXB1.2 (I7), MUXC1.2 (I7), MUXD1.2 (I7)
/E8: J2.1, MUXA1.23 (I8), MUXB1.23 (I8), MUXC1.23 (I8), MUXD1.23 (I8)
/E9: J2.2, MUXA1.22 (I9), MUXB1.22 (I9), MUXC1.22 (I9), MUXD1.22 (I9)
/E10: J2.3, MUXA1.21 (I10), MUXB1.21 (I10), MUXC1.21 (I10), MUXD1.21 (I10)
/E11: J2.4, MUXA1.20 (I11), MUXB1.20 (I11), MUXC1.20 (I11), MUXD1.20 (I11)
/E12: J2.5, MUXA1.19 (I12), MUXB1.19 (I12), MUXC1.19 (I12), MUXD1.19 (I12)
/E13: J2.6, MUXA1.18 (I13), MUXB1.18 (I13), MUXC1.18 (I13), MUXD1.18 (I13)
/E14: J2.7, MUXA1.17 (I14), MUXB1.17 (I14), MUXC1.17 (I14), MUXD1.17 (I14)
/E15: J2.8, MUXA1.16 (I15), MUXB1.16 (I15), MUXC1.16 (I15), MUXD1.16 (I15)
/Net-(A2-D20/SDA): A2.23 (A4), J3.3, U1.9 (SDA)
/Net-(A2-D21/SCL): A2.24 (A5), J3.4, U1.10 (SCL)
/Net-(A2-D50_MISO): A2.15 (D12), J5.3
/Net-(A2-D51_MOSI): A2.14 (D11), J5.4
/Net-(A2-D52_SCK): A2.16 (D13), J5.5
/Net-(A2-D53_CS): A2.13 (D10), J5.6
GND: A2.4 (GND), A2.29 (GND), C1.2, C2.1, C3.1, C4.1, C5.2, C6.1, C7.2, C8.1, C9.1, C10.2, C11.2, C12.2, C13.2, C14.2, C15.2, C16.1, C17.1, C18.1, J3.1, J5.2, MUXA1.12 (GND), MUXA1.15 (~E), MUXB1.12 (GND), MUXB1.15 (~E), MUXC1.12 (GND), MUXC1.15 (~E), MUXD1.12 (GND), MUXD1.15 (~E), R8.2, U1.1 (ADDR), U1.3 (GND), U2.4 (Vs-), U3.1 (SENSE_A), U3.8 (GND), U3.11 (EnB), U3.15 (SENSE_B), U5.4 (V-), U5.5 (+), U6.8 (GND), U6.13 (~OE), U7.8 (GND), U7.13 (~OE), U8.8 (GND), U8.13 (~OE), VINJ1.2
unnamed: A2.5 (D2), U6.11 (SRCLK), U7.11 (SRCLK), U8.11 (SRCLK)
unnamed: A2.6 (D3), U6.12 (RCLK), U7.12 (RCLK), U8.12 (RCLK)
unnamed: A2.7 (D4), U6.14 (SER)
unnamed: MUXA1.1 (COM), U3.2 (OUT1)
unnamed: MUXA1.10 (S0), U6.15 (QA)
unnamed: MUXA1.11 (S1), U6.1 (QB)
unnamed: MUXA1.14 (S2), U6.2 (QC)
unnamed: MUXA1.13 (S3), U6.3 (QD)
unnamed: MUXB1.1 (COM), R3.1, R4.1
unnamed: MUXB1.10 (S0), U6.4 (QE)
unnamed: MUXB1.11 (S1), U6.5 (QF)
unnamed: MUXB1.14 (S2), U6.6 (QG)
unnamed: MUXB1.13 (S3), U6.7 (QH)
unnamed: MUXC1.1 (COM), R1.1
unnamed: MUXC1.10 (S0), U7.15 (QA)
unnamed: MUXC1.11 (S1), U7.1 (QB)
unnamed: MUXC1.14 (S2), U7.2 (QC)
unnamed: MUXC1.13 (S3), U7.3 (QD)
unnamed: MUXD1.1 (COM), R2.1
unnamed: MUXD1.10 (S0), U7.4 (QE)
unnamed: MUXD1.11 (S1), U7.5 (QF)
unnamed: MUXD1.14 (S2), U7.6 (QG)
unnamed: MUXD1.13 (S3), U7.7 (QH)
unnamed: R6.1, U2.1 (Rg)
unnamed: R6.2, U2.8 (Rg)
unnamed: R9.2, U2.6
unnamed: R9.1, U1.4 (AIN0)
unnamed: R5.2, U1.6 (AIN2)
unnamed: R4.2, U1.7 (AIN3)
unnamed: R1.2, U2.3 (+)
unnamed: R2.2, U2.2 (-)
unnamed: C11.1, U2.5 (Ref), U5.1, U5.2 (-)
unnamed: U3.5 (IN1), U8.15 (QA)
unnamed: U3.7 (IN2), U8.1 (QB)
unnamed: R3.2, R5.1, U3.3 (OUT2)
unnamed: C8.2, C10.1, U3.4 (Vs), VINJ1.1
unnamed: R7.2, R8.1, U5.3 (+)
unnamed: U5.6 (-), U5.7
unnamed: U6.9 (QH'), U7.14 (SER)
unnamed: U7.9 (QH'), U8.14 (SER)

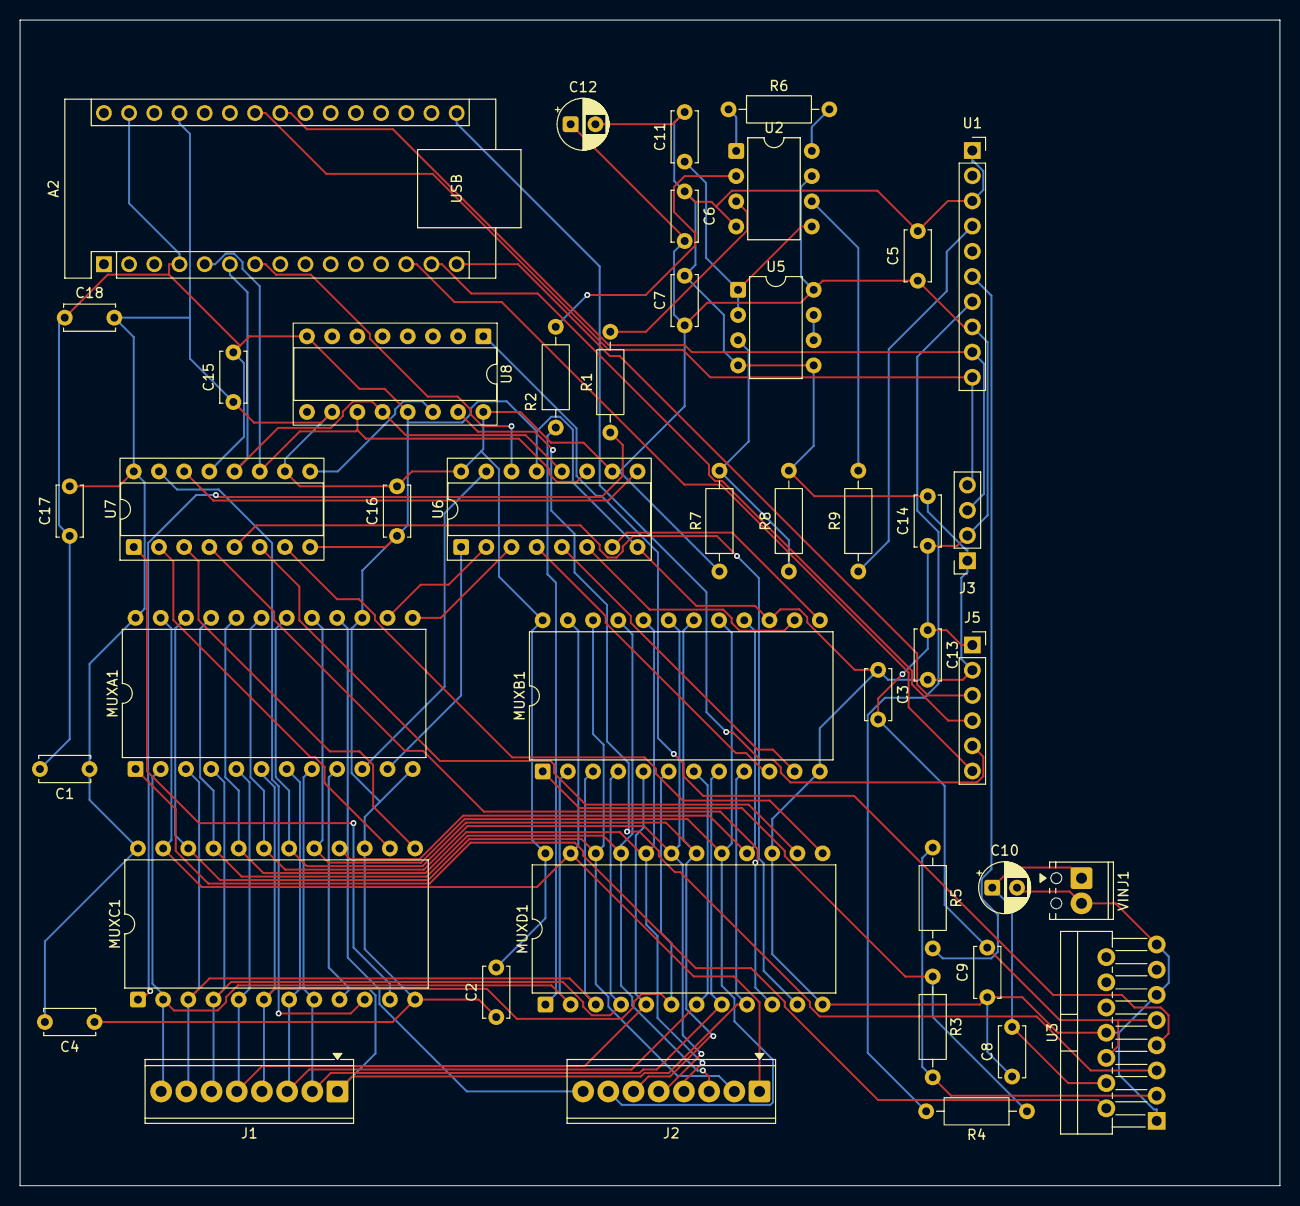
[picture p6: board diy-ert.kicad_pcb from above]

Board: 2 copper layers, 127.0 x 117.5 mm, 44 parts (0 on the bottom side), 64 nets.

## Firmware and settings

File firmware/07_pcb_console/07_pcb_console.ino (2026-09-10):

// 07: PCB console
// Firmware for the custom PCB (hardware/kicad): an Arduino Nano driving
// the four multiplexers and the L298N through three chained 74HC595
// shift registers. One sketch, driven by serial commands, covering the
// same bring-up steps as sketches 01-06 on the breadboard build. Sketch
// 00 (I2C scanner) works unchanged on the Nano.
//
// Commands, 9600 baud:
//   ?           help
//   r           raw ADC readout once (A0 amp output, A2-A3 shunt)
//   p           park the bridge (both L298N inputs low)
//   +           hold the bridge forward, DC, for multimeter work
//   -           hold the bridge reverse
//   c N         put all four muxes on channel N (0-15), for continuity checks
//   x A B C D   set mux channels individually: C1=A, C2=B, P1=C, P2=D
//   t           live amplifier readout, alternating polarity; any key stops
//   m           one stacked measurement on the current channels, prints R
//   w           Wenner survey over CH[], prints a pyGIMLi data file
//
// Shift register chain (hardware/README.md): Nano D4 -> U6 -> U7 -> U8.
//   U6  QA-QD = MUX A S0-S3,  QE-QH = MUX B S0-S3
//   U7  QA-QD = MUX C S0-S3,  QE-QH = MUX D S0-S3
//   U8  QA = L298N IN1,       QB = L298N IN2
// The 595 outputs are live from power-on (~OE is tied to ground on the
// board) and their power-up contents are undefined, so setup() latches a
// parked, known state before doing anything else.

#include <Wire.h>
#include <Adafruit_ADS1X15.h>

const int PIN_SRCLK = 2;  // 74HC595 SRCLK, all three registers
const int PIN_RCLK  = 3;  // 74HC595 RCLK, all three registers
const int PIN_SER   = 4;  // 74HC595 SER of U6, first in the chain

const int N_STACK = 20;
const int SETTLE_MS = 100;            // half-cycle ~150 ms including the read
const float SHUNT_OHMS = 1000.0;      // R3; measure the real value
const float ELECTRODE_SPACING = 0.5;  // metres between adjacent electrodes

// AD620 gain is fixed by R6 = 1k on the board: G = 1 + 49.4k/R6 = 50.4
// nominal. Measure it (docs/calibration.md) and put the measured value
// here. There is no trimmer on the PCB; change R6 to change the gain.
const float AMP_GAIN = 50.4;

// Electrode position (0-15 along the line) -> mux channel. All 16 channels
// are expected to work on the PCB; the breadboard's dead channels were
// contact faults. Edit this table if the 'c' scan finds a bad channel.
const int CH[16] = {0, 1, 2, 3, 4, 5, 6, 7, 8, 9, 10, 11, 12, 13, 14, 15};
const int N_ELECTRODES = 16;

Adafruit_ADS1115 ads;

byte regAB = 0;      // U6: MUX A channel in bits 0-3, MUX B in bits 4-7
byte regCD = 0;      // U7: MUX C channel in bits 0-3, MUX D in bits 4-7
byte regBridge = 0;  // U8: bit 0 = IN1, bit 1 = IN2

int curC1 = 0, curC2 = 3, curP1 = 1, curP2 = 2;

float lastVMN = 0.0;
float lastI = 0.0;
bool lastSuspect = false;

// ---------------------------------------------------------------- outputs

void latch() {
  digitalWrite(PIN_RCLK, LOW);
  // The first byte shifted out travels furthest and lands in U8.
  shiftOut(PIN_SER, PIN_SRCLK, MSBFIRST, regBridge);
  shiftOut(PIN_SER, PIN_SRCLK, MSBFIRST, regCD);
  shiftOut(PIN_SER, PIN_SRCLK, MSBFIRST, regAB);
  digitalWrite(PIN_RCLK, HIGH);
}

void setMuxes(int c1, int c2, int p1, int p2) {
  curC1 = c1; curC2 = c2; curP1 = p1; curP2 = p2;
  regAB = (c1 & 0x0F) | ((c2 & 0x0F) << 4);
  regCD = (p1 & 0x0F) | ((p2 & 0x0F) << 4);
  latch();
}

void bridgeForward() { regBridge = 0b01; latch(); }  // OUT1 high: C1 positive
void bridgeReverse() { regBridge = 0b10; latch(); }
void bridgePark()    { regBridge = 0b00; latch(); }  // no drive between measurements

// ----------------------------------------------------------------- inputs

float readAmpVolts() {
  return ads.computeVolts(ads.readADC_SingleEnded(0));
}

float readShuntAmps() {
  return fabs(ads.computeVolts(ads.readADC_Differential_2_3())) / SHUNT_OHMS;
}

// Two signs of a bad reading, both seen on the breadboard build: the two
// half-cycles reading nearly the same voltage (amp saturated or an input
// floating), or the output sitting within 0.2 V of a rail.
bool suspect(float vPlus, float vMinus) {
  if (fabs(vPlus - vMinus) < 0.02) return true;
  if (vPlus < 0.2 || vPlus > 4.8 || vMinus < 0.2 || vMinus > 4.8) return true;
  return false;
}

// ------------------------------------------------------------ measurement

float measureOhms(bool verbose) {
  float vSum = 0.0;  // accumulators initialised; uninitialised floats are garbage
  float iSum = 0.0;
  lastSuspect = false;

  for (int n = 1; n <= N_STACK; n++) {
    bridgeForward();
    delay(SETTLE_MS);
    float vPlus = readAmpVolts();
    float iPlus = readShuntAmps();

    bridgeReverse();
    delay(SETTLE_MS);
    float vMinus = readAmpVolts();
    float iMinus = readShuntAmps();

    if (suspect(vPlus, vMinus)) lastSuspect = true;

    vSum += (vPlus - vMinus);        // offset cancels; signal doubles
    iSum += (iPlus + iMinus) * 0.5;  // shunt read in both polarities, magnitudes averaged

    if (verbose) {
      Serial.print(F("cycle "));
      Serial.print(n);
      Serial.print(F("/"));
      Serial.print(N_STACK);
      Serial.print(F("  V+ "));
      Serial.print(vPlus, 4);
      Serial.print(F("  V- "));
      Serial.print(vMinus, 4);
      Serial.print(F("  I "));
      Serial.print((iPlus + iMinus) * 0.5 * 1000.0, 4);
      Serial.println(F(" mA"));
    }
  }
  bridgePark();

  lastVMN = (vSum / N_STACK) / (2.0 * AMP_GAIN);
  lastI   = iSum / N_STACK;
  return lastVMN / lastI;
}

// --------------------------------------------------------------- commands

void printHelp() {
  Serial.println(F("diy-ert PCB console. Commands:"));
  Serial.println(F("  ?          help"));
  Serial.println(F("  r          raw ADC readout once"));
  Serial.println(F("  p  +  -    bridge: park / hold forward / hold reverse"));
  Serial.println(F("  c N        all muxes to channel N (0-15)"));
  Serial.println(F("  x A B C D  mux channels: C1=A C2=B P1=C P2=D"));
  Serial.println(F("  t          live amp readout, any key stops"));
  Serial.println(F("  m          stacked measurement on current channels"));
  Serial.println(F("  w          Wenner survey, pyGIMLi output"));
}

void cmdRaw() {
  int16_t a0  = ads.readADC_SingleEnded(0);
  int16_t d23 = ads.readADC_Differential_2_3();
  Serial.print(F("A0 "));
  Serial.print(a0);
  Serial.print(F(" ("));
  Serial.print(ads.computeVolts(a0), 4);
  Serial.print(F(" V)   A2-A3 "));
  Serial.print(d23);
  Serial.print(F(" ("));
  Serial.print(ads.computeVolts(d23), 4);
  Serial.println(F(" V)"));
}

void cmdLive() {
  Serial.println(F("Live readout. Any key stops."));
  while (!Serial.available()) {
    bridgeForward();
    delay(SETTLE_MS);
    float vFwd = readAmpVolts();
    float iFwd = readShuntAmps();
    bridgeReverse();
    delay(SETTLE_MS);
    float vRev = readAmpVolts();
    float iRev = readShuntAmps();

    Serial.print(F("FWD "));
    Serial.print(vFwd, 4);
    Serial.print(F(" V   REV "));
    Serial.print(vRev, 4);
    Serial.print(F(" V   diff "));
    Serial.print(vFwd - vRev, 4);
    Serial.print(F(" V   I "));
    Serial.print((iFwd + iRev) * 0.5 * 1000.0, 3);
    Serial.print(F(" mA"));
    if (suspect(vFwd, vRev)) Serial.print(F("   <-- suspect: saturated, floating, or at a rail"));
    Serial.println();
  }
  while (Serial.available()) Serial.read();
  bridgePark();
  Serial.println(F("Stopped, bridge parked."));
}

void cmdMeasure() {
  Serial.print(F("Measuring on C1="));
  Serial.print(curC1);
  Serial.print(F(" C2="));
  Serial.print(curC2);
  Serial.print(F(" P1="));
  Serial.print(curP1);
  Serial.print(F(" P2="));
  Serial.println(curP2);

  float r = measureOhms(true);

  Serial.println(F("---"));
  Serial.print(F("V(P1-P2) = "));
  Serial.print(lastVMN * 1000.0, 3);
  Serial.println(F(" mV"));
  Serial.print(F("I        = "));
  Serial.print(lastI * 1000.0, 4);
  Serial.println(F(" mA"));
  Serial.print(F("R        = "));
  Serial.print(r, 2);
  Serial.println(F(" ohm"));
  if (lastSuspect) {
    Serial.println(F("WARNING: at least one half-cycle looked saturated or at a rail. Do not trust R."));
  }
}

void cmdSurvey() {
  // pyGIMLi unified data format; the serial stream is the data file.
  Serial.println(N_ELECTRODES);
  Serial.println(F("# x z"));
  for (int i = 0; i < N_ELECTRODES; i++) {
    Serial.print(i * ELECTRODE_SPACING, 2);
    Serial.println(F(" 0.0"));
  }

  int total = 0;
  for (int n = 1; 3 * n < N_ELECTRODES; n++) total += N_ELECTRODES - 3 * n;
  Serial.println(total);
  Serial.println(F("# a b m n rhoa"));

  for (int n = 1; 3 * n < N_ELECTRODES; n++) {
    for (int i = 0; i + 3 * n < N_ELECTRODES; i++) {
      int c1 = i, p1 = i + n, p2 = i + 2 * n, c2 = i + 3 * n;
      setMuxes(CH[c1], CH[c2], CH[p1], CH[p2]);
      delay(10);
      float r = measureOhms(false);
      float rhoa = 2.0 * PI * (n * ELECTRODE_SPACING) * r;
      Serial.print(c1 + 1);
      Serial.print(F(" "));
      Serial.print(c2 + 1);
      Serial.print(F(" "));
      Serial.print(p1 + 1);
      Serial.print(F(" "));
      Serial.print(p2 + 1);
      Serial.print(F(" "));
      Serial.println(rhoa, 3);
    }
  }
  Serial.println(F("0"));
}

// ------------------------------------------------------------------- main

void setup() {
  pinMode(PIN_SRCLK, OUTPUT);
  pinMode(PIN_RCLK, OUTPUT);
  pinMode(PIN_SER, OUTPUT);
  digitalWrite(PIN_SRCLK, LOW);
  digitalWrite(PIN_RCLK, LOW);
  bridgePark();                 // latch a known, parked state immediately
  setMuxes(curC1, curC2, curP1, curP2);

  Serial.begin(9600);
  Serial.setTimeout(2000);
  if (!ads.begin(0x48)) {
    Serial.println(F("ADS1115 not found at 0x48. Run sketch 00, check the socket."));
    while (true) {}
  }
  ads.setGain(GAIN_TWOTHIRDS);  // 0-5 V amp output needs the +/-6.144 V range
  printHelp();
}

void loop() {
  if (!Serial.available()) return;
  char c = Serial.read();
  switch (c) {
    case '?': printHelp(); break;
    case 'r': cmdRaw(); break;
    case 'p': bridgePark();    Serial.println(F("PARKED.")); break;
    case '+': bridgeForward(); Serial.println(F("FORWARD, holding DC.")); break;
    case '-': bridgeReverse(); Serial.println(F("REVERSE, holding DC.")); break;
    case 'c': {
      int n = Serial.parseInt();
      setMuxes(n, n, n, n);
      Serial.print(F("All muxes on channel "));
      Serial.println(n);
      break;
    }
    case 'x': {
      int a = Serial.parseInt();
      int b = Serial.parseInt();
      int cc = Serial.parseInt();
      int d = Serial.parseInt();
      setMuxes(a, b, cc, d);
      Serial.print(F("C1="));  Serial.print(a);
      Serial.print(F(" C2=")); Serial.print(b);
      Serial.print(F(" P1=")); Serial.print(cc);
      Serial.print(F(" P2=")); Serial.println(d);
      break;
    }
    case 't': cmdLive(); break;
    case 'm': cmdMeasure(); break;
    case 'w': cmdSurvey(); break;
    default: break;  // ignore line endings and unknown characters
  }
}

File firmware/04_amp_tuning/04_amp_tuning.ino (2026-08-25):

// 04: Live amplifier tuning
// Verifies: the AD620 is operating inside its input range and its output
// responds to both injection polarities.
//
// Wire the symmetric bench chain (docs/hardware.md, constraint 3) and run
// this while adjusting the trimmers. Follow the order in
// docs/calibration.md: offset FIRST, with no current flowing; then gain.
//
// Failure signature: both half-cycles reading ~3.6 V means the amp is
// saturated. That is an offset problem, not a gain problem; the gain
// trimmer changes nothing while the output is pinned.
//
// Healthy output after calibration: the two polarities land around 1.5 V
// and 3.5 V, clearly separated, not clipping either rail.

#include <Wire.h>
#include <Adafruit_ADS1X15.h>

const int BRIDGE_IN1 = 6;
const int BRIDGE_IN2 = 7;

const int MUX_C1[4] = {22, 24, 26, 28};
const int MUX_C2[4] = {30, 32, 34, 36};
const int MUX_P1[4] = {38, 40, 42, 44};
const int MUX_P2[4] = {46, 48, 50, 52};

// Mux channels the bench chain is wired to. Change to match your wiring;
// avoid channels your sketch-03 scan found dead.
const int C1_CHANNEL = 1;
const int C2_CHANNEL = 2;
const int P1_CHANNEL = 3;
const int P2_CHANNEL = 4;

const int SETTLE_MS = 100;         // half-cycle ~150 ms including the read
const float SHUNT_OHMS = 1000.0;

Adafruit_ADS1115 ads;

void setMux(const int pins[4], int channel) {
  for (int b = 0; b < 4; b++) {
    digitalWrite(pins[b], (channel >> b) & 1);
  }
}

void bridgeForward() {
  digitalWrite(BRIDGE_IN1, HIGH);
  digitalWrite(BRIDGE_IN2, LOW);
}

void bridgeReverse() {
  digitalWrite(BRIDGE_IN1, LOW);
  digitalWrite(BRIDGE_IN2, HIGH);
}

void setup() {
  pinMode(BRIDGE_IN1, OUTPUT);
  pinMode(BRIDGE_IN2, OUTPUT);
  digitalWrite(BRIDGE_IN1, LOW);
  digitalWrite(BRIDGE_IN2, LOW);
  for (int b = 0; b < 4; b++) {
    pinMode(MUX_C1[b], OUTPUT);
    pinMode(MUX_C2[b], OUTPUT);
    pinMode(MUX_P1[b], OUTPUT);
    pinMode(MUX_P2[b], OUTPUT);
  }
  setMux(MUX_C1, C1_CHANNEL);
  setMux(MUX_C2, C2_CHANNEL);
  setMux(MUX_P1, P1_CHANNEL);
  setMux(MUX_P2, P2_CHANNEL);

  Serial.begin(9600);
  while (!Serial) {}
  if (!ads.begin(0x48)) {
    Serial.println("ADS1115 not found at 0x48. Go back to sketch 00.");
    while (true) {}
  }
  ads.setGain(GAIN_TWOTHIRDS);  // 0-5 V amp output needs the +/-6.144 V range
  Serial.println("Live tuning. Adjust offset first, then gain.");
}

void loop() {
  bridgeForward();
  delay(SETTLE_MS);
  float vFwd = ads.computeVolts(ads.readADC_SingleEnded(0));
  float iFwd = fabs(ads.computeVolts(ads.readADC_Differential_2_3())) / SHUNT_OHMS;

  bridgeReverse();
  delay(SETTLE_MS);
  float vRev = ads.computeVolts(ads.readADC_SingleEnded(0));
  float iRev = fabs(ads.computeVolts(ads.readADC_Differential_2_3())) / SHUNT_OHMS;

  Serial.print("FWD ");
  Serial.print(vFwd, 4);
  Serial.print(" V   REV ");
  Serial.print(vRev, 4);
  Serial.print(" V   diff ");
  Serial.print(vFwd - vRev, 4);
  Serial.print(" V   I ");
  Serial.print((iFwd + iRev) * 0.5 * 1000.0, 3);
  Serial.println(" mA");
}

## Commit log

2026-08-25 Initial commit: DIY-ERT documentation, firmware, and analysis
    Four-electrode Wenner resistivity meter. Bench-validated single-point
    measurement (98.6 ohm on a 100 ohm reference); one field reading
    (71-72 ohm-m, Georgia clay). Includes the failure log, seven ordered
    bring-up sketches, PCB status, and pyGIMLi inversion pipeline.
    [00_i2c_scanner.ino, 01_raw_adc.ino, 02_dc_hold.ino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]
2026-08-25 Rewrite docs in plainer prose and add wiring reference
    Strip em dashes and typographic characters throughout. Add a mermaid
    block diagram, results table, and status checklist to the README, and a
    wiring reference (injection path, sense path, mid-rail reference, pinout
    tables for the AD620, ADS1115, and muxes) to docs/hardware.md. Move the
    bench chain schematic into docs/calibration.md.
2026-09-10 Add PCB design files, build guide, software guide, and PCB firmware
    hardware/: KiCad 10 sources (renamed from Untitled, verified against the
    original by netlist, ERC, DRC and gerber comparison), regenerated gerbers
    and drill, schematic PDF and PNG, board renders, BOM, DRC/ERC reports,
    and a rewritten README with board specs, shift register wiring, pin maps,
    fabrication notes, history, and review notes (ADS1115 socket pin order,
    595 power-on state, fixed gain headroom, C10 polarity).
    docs/assembly.md: power, floorplan, full pin-by-pin connection list from
    the netlist for both builds, assembly order, electrode line, checklist.
    docs/software.md: toolchain, upload, bring-up walkthrough for bot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
    [bom.csv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]
